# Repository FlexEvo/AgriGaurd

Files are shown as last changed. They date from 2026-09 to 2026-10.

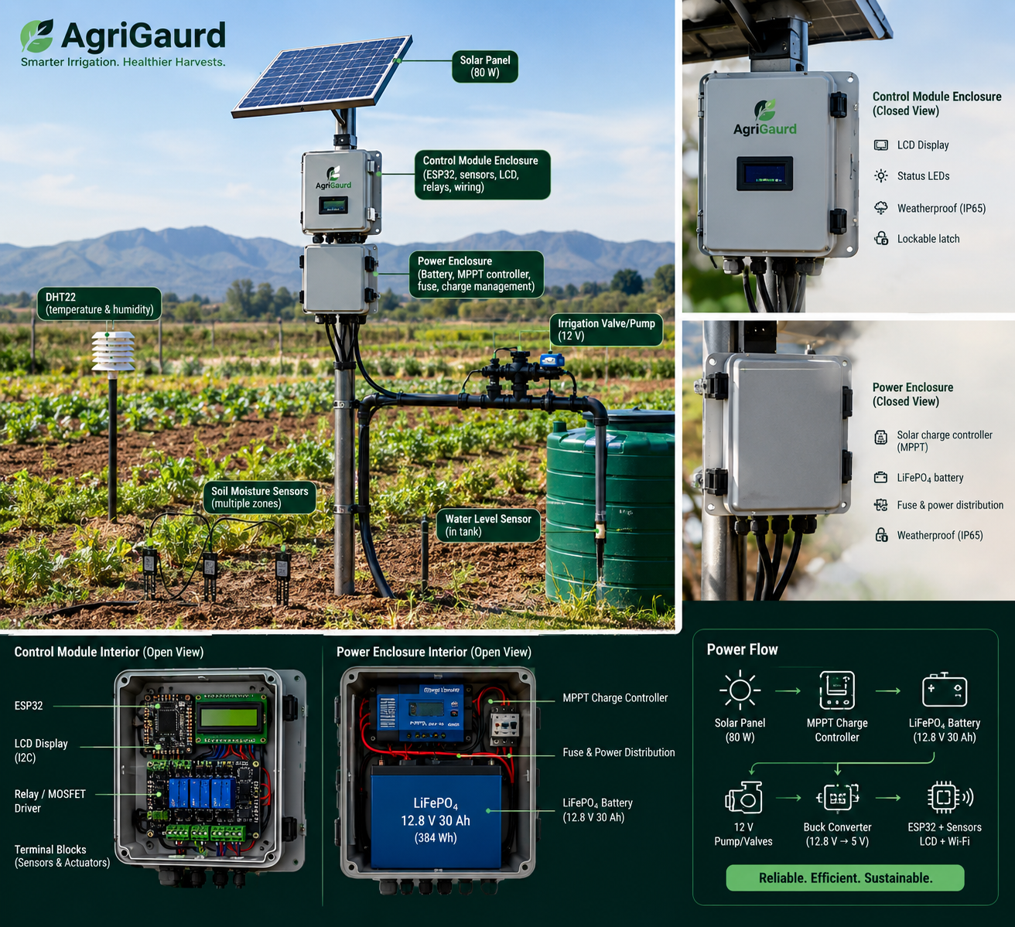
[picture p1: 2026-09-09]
Data structures/FOLDERZ_B/AgriGaurd Smart Irrigation System.png

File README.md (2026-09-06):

# 🌱 AgriGuard — Smart Irrigation & Water Management System

AgriGuard is a smart irrigation system designed to help small-scale farmers **use water more efficiently while maintaining suitable soil conditions for crop growth**.

The system combines soil-moisture sensing, environmental monitoring, automated irrigation, weather information, and historical irrigation data to make better decisions about **when, where, and how much water should be supplied**.

Rather than relying on a simple fixed irrigation schedule, AgriGuard is being developed toward an **adaptive, zone-based irrigation system** that can learn the behaviour of individual areas of a farm and use that information to improve future irrigation decisions.

---

## 🎯 Project Objective

The main objective of AgriGuard is:

> **To reduce unnecessary water consumption while providing crops with the water they need.**

Traditional automated irrigation systems can operate using fixed timers or simple moisture thresholds. While this works, it does not account well for differences between zones, soil types, environmental conditions, or available water.

AgriGuard addresses this by building an irrigation profile for each zone.

The system considers factors such as:

* Soil moisture
* Soil type
* Temperature
* Humidity
* Rainfall/weather conditions
* Soil drying rate
* Irrigation duration
* Water consumption
* Available tank water
* Historical irrigation behaviour

These factors are used to make more informed irrigation decisions.

---

# 🧠 How the Solution Works

At a high level, AgriGuard follows this process:

```text
             ┌─────────────────────┐
             │      Sensors        │
             │                     │
             │ Soil Moisture       │
             │ Temperature         │
             │ Humidity            │
             │ Water Level         │
             │ Flow Rate           │
             └──────────┬──────────┘
                        │
                        ▼
             ┌─────────────────────┐
             │       ESP32         │
             │   Control System    │
             └──────────┬──────────┘
                        │
          ┌─────────────┼─────────────┐
          ▼             ▼             ▼
   Soil Analysis   Environment    Water Status
          │             │             │
          └─────────────┼─────────────┘
                        ▼
             ┌─────────────────────┐
             │ Irrigation Decision │
             │      Algorithm       │
             └──────────┬──────────┘
                        │
                        ▼
             ┌─────────────────────┐
             │   Zone Control      │
             │                     │
             │ Valve / Pump        │
             └──────────┬──────────┘
                        │
                        ▼
                 Irrigation Cycle
                        │
                        ▼
             ┌─────────────────────┐
             │ Historical Data     │
             │ & Zone Profile      │
             └──────────┬──────────┘
                        │
                        ▼
             Improve Future Decisions
```

---

# ⚙️ System Architecture

AgriGuard is divided into several major sections.

### 1. Soil Monitoring

Capacitive soil-moisture sensors are used to monitor the moisture condition of different irrigation zones.

The system does not treat the raw sensor reading as a direct percentage. Instead, calibration values are used to convert sensor readings into a more meaningful moisture representation.

The calibration process considers conditions such as:

* Dry soil
* Wet soil
* Soil type
* Sensor behaviour

Multiple sensors can be deployed across different zones to provide a more representative view of the farm.

---

### 2. Environmental Monitoring

Environmental conditions can affect how quickly soil loses moisture.

AgriGuard therefore incorporates environmental data such as:

* Temperature
* Relative humidity
* Precipitation
* Weather forecasts

Weather data is treated as an **additional decision-making factor rather than a single point of failure**.

If weather data is unavailable, the system can continue operating using the locally measured sensor data.

---

### 3. Zone-Based Irrigation

The farm is divided into irrigation zones.

Each zone can have its own:

* Soil type
* Moisture readings
* Drying behaviour
* Irrigation history
* Valve status
* Irrigation duration
* Water consumption
* Calibration values

This allows AgriGuard to recognise that different areas of a farm may require different irrigation strategies.

For example:

```text
Zone 1 → Sandy soil → dries quickly
Zone 2 → Loamy soil → moderate drying
Zone 3 → Clay soil  → dries slowly
```

Instead of treating the entire farm identically, the controller can make decisions based on the behaviour of each zone.

---

# 💧 Adaptive Irrigation

One of the main developments of AgriGuard is moving beyond a simple:

```text
IF soil is dry
    irrigate
```

approach.

The system is being developed to consider both **current conditions and historical behaviour**.

A simplified decision can be represented as:

```text
Current Soil Condition
          +
Environmental Conditions
          +
Zone Drying Behaviour
          +
Expected Weather
          +
Available Water
          ↓
   Irrigation Decision
```

This creates the foundation for adaptive irrigation.

---

# 📈 Zone Irrigation Profile

AgriGuard records information about how each irrigation zone behaves over time.

The zone profile can include:

* Moisture readings
* Moisture change over time
* Drying rate
* Temperature during drying
* Irrigation duration
* Irrigation frequency
* Water used
* Previous irrigation cycles

The purpose is to determine patterns such as:

> "How quickly does this zone dry after irrigation?"

and:

> "How much water does this zone normally require?"

This information can then be used to improve future irrigation decisions.

---

# 💦 Water Budget

Another major component of AgriGuard is the **water budget**.

The system considers:

```text
Available Water
       ↓
Water Required by Zones
       ↓
Zone Priority
       ↓
Water Allocation
       ↓
Irrigation
```

This is particularly important when the available water supply is limited.

Instead of simply irrigating every zone whenever its moisture falls below a threshold, AgriGuard can determine how available water should be allocated.

The long-term goal is to answer:

> **"Given the amount of water currently available, where will using that water provide the greatest benefit?"**

---

# 🧠 Learning Irrigation Cycles

AgriGuard is being developed toward a system that can learn from previous irrigation cycles.

After an irrigation event, the system can monitor:

```text
Irrigation starts
       ↓
Water is supplied
       ↓
Irrigation stops
       ↓
Soil moisture is monitored
       ↓
Drying rate is calculated
       ↓
Data is stored
       ↓
Future irrigation decisions improve
```

This allows the system to gradually build an understanding of each zone rather than relying entirely on manually configured values.

---

# 🚨 Safety System

AgriGuard also includes an emergency-stop mechanism.

The emergency stop is designed to provide a physical safety mechanism capable of shutting down the irrigation system when activated.

The emergency function is treated separately from the normal irrigation decision logic so that safety takes priority.

Conceptually:

```text
              Emergency Stop
                    │
                    ▼
          ┌──────────────────┐
          │ System Shutdown  │
          └────────┬─────────┘
                   │
          Normal operation
             is disabled
```

The design also considers the interaction between the physical latching switch, ESP32 control logic, and irrigation power-control circuitry.

---

# 🔌 Hardware

The system has been designed around an **ESP32 development board** as the main controller.

Major hardware components include:

* ESP32 development board
* Capacitive soil-moisture sensors
* Temperature/humidity sensor
* Water-level sensor
* Water-flow sensor
* Solenoid/flow valves
* Pump/control circuitry
* LCD display
* Emergency-stop switch
* Power supply
* Protective sensor enclosures

The exact hardware configuration may evolve as the prototype is developed and tested.

---

# 💻 Software

The embedded software is being developed primarily using **C++ for the Arduino/ESP32 environment**.

The software is structured into separate functional sections so that each subsystem can be developed and tested independently before being integrated into the main program.

Major software components include:

```text
Sensor acquisition
      ↓
Data processing
      ↓
Calibration
      ↓
Zone management
      ↓
Drying-rate analysis
      ↓
Weather processing
      ↓
Irrigation decision
      ↓
Valve control
      ↓
Water-budget management
      ↓
Historical data
```

Data structures such as `enum` and `struct` are used to represent things such as:

* Soil types
* Irrigation zones
* Water tanks
* Sensor data
* Valve states
* Calibration parameters

This makes the system easier to expand as additional zones and sensors are introduced.

---

# 🌦️ Weather Integration

AgriGuard can retrieve weather information through an online weather API.

The weather subsystem has been designed to provide information such as:

* Temperature
* Relative humidity
* Precipitation
* Probability of precipitation

This information can be incorporated into irrigation decisions.

For example, if a zone is approaching its irrigation threshold but significant rainfall is expected, the system can consider reducing or delaying irrigation.

Weather information therefore acts as a **decision-enhancement layer**, rather than being required for the system to function.

---

# 🛠️ Development Approach

The system has been developed incrementally rather than attempting to build the complete system at once.

The development process has broadly followed:

```text
1. Identify the irrigation problem
            ↓
2. Select sensors and hardware
            ↓
3. Develop individual sensor modules
            ↓
4. Develop ESP32 control logic
            ↓
5. Develop soil calibration
            ↓
6. Introduce multiple irrigation zones
            ↓
7. Add environmental data
            ↓
8. Develop irrigation thresholds
            ↓
9. Implement water monitoring
            ↓
10. Measure irrigation cycles
            ↓
11. Build zone irrigation profiles
            ↓
12. Develop water budgeting
            ↓
13. Introduce adaptive/learning behaviour
            ↓
14. Integrate safety systems
            ↓
15. Package the system into physical hardware
```

The project therefore combines **embedded systems, electronics, software engineering, data processing, control systems, and physical product design**.

# 🚀 Long-Term Vision

The long-term goal of AgriGuard is not simply to automate irrigation.

It is to create a system that can **understand how a farm uses water and continuously improve how that water is allocated.**

The intended progression is:

```text
Automated Irrigation
        ↓
Zone-Based Irrigation
        ↓
Data-Driven Irrigation
        ↓
Adaptive Irrigation
        ↓
Water-Budget Optimisation
        ↓
Self-Improving Irrigation System
```

AgriGuard is therefore being developed as a platform where **sensing, control, data and physical infrastructure work together** to make irrigation more efficient.

---

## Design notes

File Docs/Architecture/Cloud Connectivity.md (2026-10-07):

# AgriGuard Cloud Connectivity Architecture

## Principle

Cloud connectivity is an enhancement layer, not a safety dependency.

```
                    AGRIGUARD ESP32
                         |
          +--------------+--------------+
          |                             |
          v                             v
   LOCAL CONTROL                 CLOUD CLIENT
          |                             |
   +------+------+              +-------+-------+
   |      |      |              |       |       |
 Soil   Tank   Valves          Wi-Fi   NTP   HTTPS
   |      |      |                      |
   +------+------+                      v
          |                     Supabase Edge Function
          |                              |
          |                     Atomic telemetry ingest
          |                              |
          v                              v
    SAFE IRRIGATION              Supabase telemetry
```

## Failure behavior

If Wi-Fi or the cloud service becomes unavailable:

1. Local soil monitoring continues.
2. Tank monitoring continues.
3. Valve/safety logic continues.
4. Cloud telemetry is marked offline.
5. The device retries according to the configured retry policy.
6. Reconnection does not require a device reboot.

## B6 retry policy

The current test configuration uses:

- maximum POST attempts: 3
- HTTP timeout: 10 seconds
- retry delays: 2 seconds, then 4 seconds
- automated Wi-Fi outage test
- automatic Wi-Fi reconnection

## B7 heartbeat

The heartbeat provides device-health information such as:

- firmware version
- uptime
- Wi-Fi state
- Wi-Fi RSSI
- cloud state
- consecutive cloud failures
- last successful cloud transmission

A successful heartbeat also updates the device's server-side last-seen information.

## Next milestone

After the corrected B6/B7 sketch receives a successful HTTP 2xx response and the corresponding Supabase rows are verified, B1-B7 can be marked as end-to-end verified.

The next major workstream is the farmer-facing profile/onboarding flow.

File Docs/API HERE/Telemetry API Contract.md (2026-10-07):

# AgriGuard Telemetry API Contract

## Endpoint

`POST /functions/v1/ingest-telemetry-v2`

The device authenticates using custom headers.

## Required headers

| Header | Purpose |
|---|---|
| `x-device-uid` | Provisioned device identifier |
| `x-device-key` | Private device credential |
| `x-request-id` | RFC 4122 UUID request identifier |
| `x-device-nonce` | Per-request replay-protection nonce |
| `x-device-timestamp` | Unix timestamp in milliseconds |

## Freshness

The Edge Function currently accepts authenticated request timestamps within approximately five minutes of server time.

## Telemetry structure

```json
{
  "heartbeat": true,
  "sensor_readings": [
    {
      "zone_id": "ZONE_UUID",
      "moisture_percent": 67.89,
      "raw_value": 1778,
      "temperature_c": 13.0,
      "humidity_percent": 63.0,
      "drying_rate": 7.96,
      "recorded_at": "2026-10-06T23:55:32Z"
    }
  ],
  "tank_reading": {
    "level_percent": 75.0,
    "volume_l": 3937.5,
    "distance_cm": 45.0,
    "recorded_at": "2026-10-06T23:55:32Z"
  },
  "system_status": {
    "status": "online",
    "message": "AgriGuard B6/B7 test",
    "battery_percent": 100,
    "wifi_rssi": -50,
    "recorded_at": "2026-10-06T23:55:32Z"
  }
}
```

## Accepted system states

- `online`
- `offline`
- `watering`
- `settling`
- `checking`
- `emergency_stop`
- `fault`

## Validation notes

- Sensor arrays may contain up to three readings per request.
- Zone IDs must be valid UUIDs and must belong to the authenticated device and its farm.
- Percentages must be between 0 and 100.
- Raw sensor values must be non-negative integers.
- Tank volume and distance must be non-negative.
- Wi-Fi RSSI must be zero or negative.
- `recorded_at` values must be valid and fresh.

## Response

Successful ingestion returns an `ok: true` response and a server-side receipt timestamp.

Failures are mapped to meaningful HTTP responses, including:

- `400` invalid payload
- `401` authentication/device state failure
- `403` unauthorized zone
- `409` replay detected
- `429` device rate limit exceeded

## Credential rule

Device credentials and farmer authentication are separate security domains.

The ESP32 device key must never be used as a farmer login credential and must never be committed to GitHub.

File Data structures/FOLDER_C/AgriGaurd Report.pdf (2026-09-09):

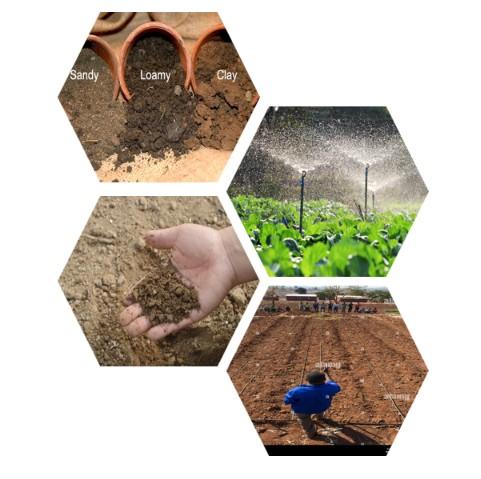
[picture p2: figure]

## AgriGaurd

## System

Table of Contents

# Problem Statement…

### 1. Background and Problem Statement

Agriculture is fundamentally dependent on water. However, water availability is becoming increasingly uncertain due to population growth, climate variability, drought and increasing competition for freshwater resources.
Agriculture currently accounts for approximately 72% of global freshwater withdrawals, with irrigation being the primary driver of agricultural water demand. At the same time, approximately 1.2 billion people live in agricultural areas experiencing severe water constraints. The Food and Agriculture Organization (FAO) estimates that by 2050 agriculture will need to produce approximately 50% more food, feed and fibre than in 2012, while freshwater demand is expected to increase by another 25%.
This creates a fundamental challenge that agriculture needs to produce more with less water. The problem is therefore not simply a shortage of water. It is also a problem of “how available water is managed and allocated.”

# The Irrigation Problem

Traditional irrigation decisions are often based on fixed schedules, timers, manual observation or farmer experience. A simplified conventional approach would look like:

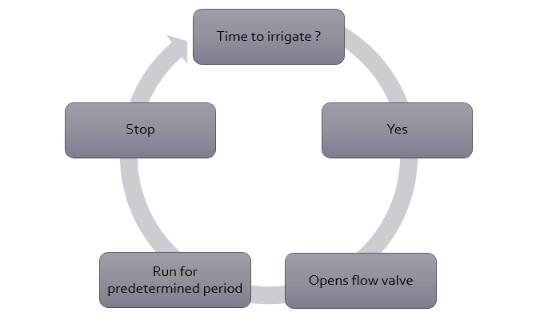
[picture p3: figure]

The problem with this approach is that the environment is not fixed, soil moisture changes continuously, temperature fluctuates, humidity changes, rainfall changes, different soils retain water differently, different zones/areas dry at different rates. Consequently, applying the same irrigation schedule to every zone can result in:
- Under-irrigation
- Over-irrigation
- Unnecessary water consumption
- Nutrient leaching
- Waterlogging
- Reduced crop performance
- Increased operating costs

The central problem identified by AgriGuard is that farmers need to make irrigation decisions using changing field conditions, but many low- and mid-scale operations lack affordable systems capable of continuously measuring, interpreting and acting on those conditions.

# How Much Water Is Being Lost

Irrigation losses occur for many reasons, including evaporation, runoff, deep percolation, poor infrastructure and inappropriate irrigation scheduling.
FAO (Farm and Agriculture Organization) indicates that 40% or more of water diverted for irrigation can be lost at farm level in some circumstances, through mechanisms such as deep percolation and surface runoff.
This does not mean that 40% of all irrigation water is universally wasted by farmers. Rather, it demonstrates the magnitude of potential losses throughout irrigation systems. Research provides stronger evidence that better scheduling can directly reduce water use. A systematic review of soil-water-sensor irrigation scheduling research found that sensor-based scheduling used, on average:

The review also found that soil-water-sensor scheduling produced 24% higher yields on average compared with traditional scheduling in the relevant comparisons. This provides an important foundation for AgriGuard, better information can result in better irrigation decisions.

Comparison | Average water reduction
Traditional scheduling | 38%
Computer-model scheduling | 16%
Evapotranspiration replacement | 20%
Canopy-temperature methods | 1%
Traditional scheduling | 38%

# Overwatering Is Also a Problem

Water conservation cannot simply mean reducing irrigation as much as possible. Plants require water, but they also require oxygen around their roots. When soil remains saturated for extended periods, oxygen availability to the root system decreases. This can impair root growth, nutrient uptake and plant development.
A global meta-analysis containing 2,419 comparisons from 115 studies found that waterlogging reduced crop yield by an average of approximately 32.9%.
Therefore, both extremes are problematic:

OR

This leads to one of the core principles behind AgriGuard:
The objective is not to give crops more water, but it is to give crops the right amount of water at the right time.

# Why Small-Scale Farmers Are Particularly Affected

The irrigation problem becomes more difficult when considering the economic and environmental conditions faced by small and mid-scale farmers.
A 2025 review specifically examining smallholder irrigation development in South Africa identified several constraints, including:
- Limited access to irrigation water
- Inadequate infrastructure
- Drought
- Limited land access
- Financial constraints
- Technological limitations
- Knowledge and skills gaps
- Challenges implementing water policies
- Climate-change impacts
These constraints interact with one another.

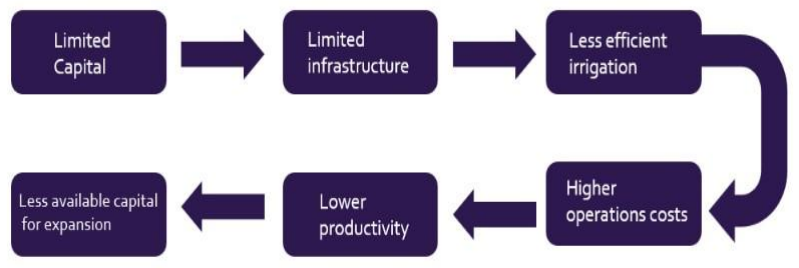
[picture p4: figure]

This creates a cycle that makes it difficult for small-scale farmers to transition toward more advanced agricultural operations.

# Economic Constraints

Small-scale farmers commonly face barriers associated with:
- Initial capital:
Advanced irrigation systems can require pumps, pipes, valves, sensors, controllers and installation.
- Operating costs:
Energy, water, maintenance and replacement components add recurring costs.
- Access to finance:
Agricultural lending can be difficult because small farms may lack collateral, have small transaction sizes and face high production and market risks.
Research on agricultural finance in Africa notes that less than 4% of total commercial bank lending goes to agriculture, with factors such as lack of collateral, remoteness, infrastructure limitations and variable rainfall contributing to lending difficulties.
- Technology cost:
Advanced precision-agriculture systems can provide excellent functionality, but their cost and complexity can make them difficult to adopt at smaller scales.

# Environmental Constraints

Small-scale farmers are also exposed to environmental uncertainty. These include:
- Drought
- Unpredictable rainfall
- Increasing temperatures
- Evaporation
- Soil variability
- Water scarcity
- Changing crop-water requirements
Climate change makes the problem more difficult because water supply becomes less predictable while crop water demand can increase. The FAO identifies climate change as a factor reducing the reliability of water supply while increasing crop water requirements. Therefore, a farmer cannot reliably depend on a fixed irrigation schedule throughout an entire growing season.

# Research Supporting the AgriGuard Concept

AgriGuard's architecture was influenced by several areas of existing research.
Research strongly supports the use of soil-water sensors for irrigation scheduling.
A 2023 systematic review analysed 97 papers, including 48 studies involving soil-water-sensor irrigation scheduling. The review found that sensor-based scheduling reduced water use while maintaining or improving yield in many comparisons.
Importantly, the review also identified calibration as one of the major factors influencing sensor accuracy. This directly influenced AgriGuard's decision not to treat a raw sensor ADC data as an automatically valid percentage.
“A percentage is only useful if we know what 0% and 100% actually mean.”

# Study on Smart Irrigation

Study into smart irrigation has expanded significantly.
A 2026 systematic review of IoT-enabled smart irrigation systems examined 50 studies and reported water savings ranging from approximately 9–50% across reviewed systems relative to conventional irrigation. The same review identified high cost, scalability and farmer training among major adoption barriers.
This is significant because it demonstrates both sides of the problem, which is that the technology works, but also the technology must also be accessible.
AgriGuard therefore attempts to combine the advantages of smart irrigation with a low-cost embedded architecture.

# Introducing AgriGuard

AgriGuard is an ESP32-based smart irrigation and water-management system designed for low to mid-scale agricultural operations.
The system consists of:
✓ | ESP32 MCU
✓ | 3 × capacitive soil-moisture sensors
✓ | 3 × solenoid irrigation valves
✓ | 4-channel relay module
✓ | Water-level sensor
✓ | LCD I2C
✓ | ON/OFF switch
✓ | Emergency-stop switch
✓ | Reset switch
✓ | Pull-up resistors
The prototype is organised around three irrigation zones. Zone 1 → Soil Sensor 1 → Valve 1
Zone 2 → Soil Sensor 2 → Valve 2
Zone 3 → Soil Sensor 3 → Valve 3
The ESP32 acts as the central processing and control unit. How AgriGaurd works:

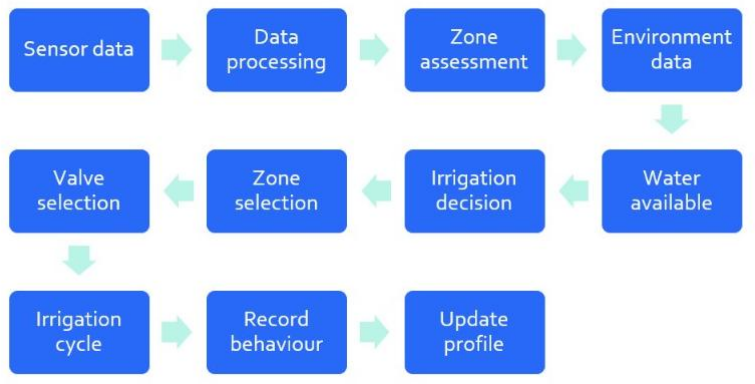
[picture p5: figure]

# . What AgriGuard Considers

AgriGuard is designed to consider several factors simultaneously. ✓ Current soil moisture:
Determines the current soil moisture of each zone.
✓ Soil type
Considers the differences in how different soils retain and release water. ✓ Drying rate
Determines how the rate at which each zone is losing moisture.
✓ Temperature
Considers how cold or hot the area is can influence the drying rate of the farm.
✓ Humidity
Looks at the moisture within the air to determine the amount of water that has left. ✓ Rainfall/weather
Can influence whether irrigation should be delayed or adjusted.
✓ Available water
Determines whether there is sufficient water in the tank for irrigation.
✓ Historical irrigation cycles
Provides information about how the zone responded to previous irrigation events.
✓ Zone priority
Allows available water to be allocated according to the current needs of different zones

# AgriGuard and Small-Scale Farmer Constraints

AgriGuard is designed specifically to help resolve the issues farmers were encountering.

AgriGuard is not attempting to solve every agricultural problem, instead, it focuses on a specific and controllable problem. Improving irrigation decision-making and water allocation.

Farmer constraint | AgriGuard response
Limited capital | Low-cost ESP32-based architecture
Limited irrigation infrastructure | Modular zone-based design
Water scarcity | Water-level monitoring and water budgeting
Unpredictable weather | Weather-assisted decision-making
Different soil types | Zone-specific calibration
Different drying rates | Drying-rate analysis
Limited technical resources | Local LCD interface
Safety concerns | Physical E-STOP and reset
Internet unreliability | Local sensor operation remains available
Need for expansion | Modular zone architecture
Limited historical data | System progressively builds irrigation profiles

# Innovation

The biggest innovation in AgriGuard is not simply automatic irrigation, it is the system's development in learning-based water budget.
The system can progressively learn:
- How quickly each zone dries
- How much irrigation each zone normally requires
- How long irrigation cycles run
- How environmental conditions influence drying
- How much water is available
- How much water different zones require
This creates the possibility of moving from, “Turn the valve on when the soil is dry", to determining on what I have learned about this zone, the current environmental conditions and the amount of water available, this zone should receive priority.
The long-term vision is to create a self-improving irrigation system.
The conceptual progression is:

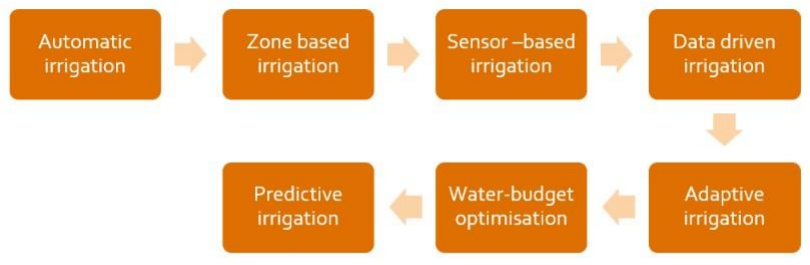
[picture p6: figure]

Future versions could use machine-learning models to predict soil moisture using historical:
- Soil moisture
- Temperature
- Humidity

- Weather
- Irrigation duration
- Water usage
Recent research is already investigating exactly this direction: soil-moisture forecasting models using historical sensor, weather and irrigation observations. The major change would be that AgriGuard would no longer wait for soil to become sufficiently dry before reacting, it would predict when a zone is likely to require water and prepare the water budget before the demand occurs.

# System Architecture

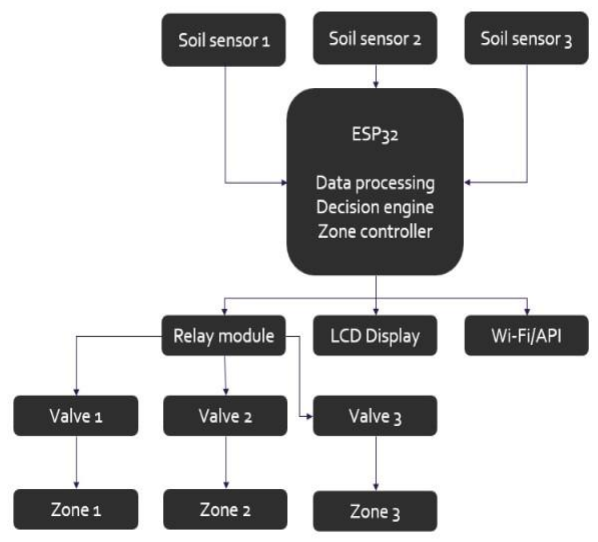
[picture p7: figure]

Water-Level Sensor ──► ESP32

ON/OFF ───────────────► ESP32 E-STOP ───────────────► Safety Logic RESET ────────────────► ESP32

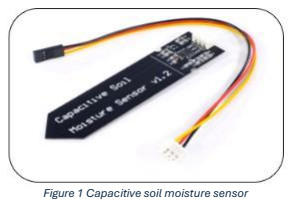
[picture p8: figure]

## Soil-Monitoring Subsystem

Three capacitive sensors provide the soil-moisture information. Each sensor is assigned to one zone. The raw analogue signal is processed by the ESP32 and converted using calibration information. The system can then monitor changes over time. This provides the basis for calculating drying rates.

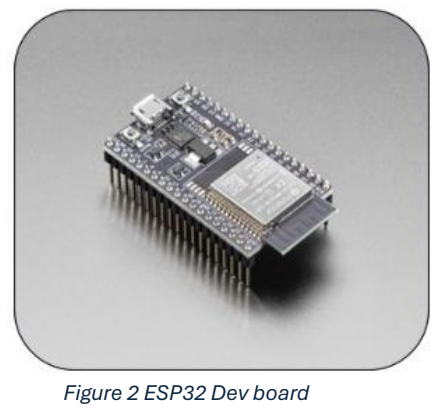
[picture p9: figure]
Figure 2 ESP32 Dev board

## Irrigation-Control Subsystem

The ESP32 is the brains of the entire operations, it handles all logical, arithmetic calculation and all processing the system will perform. The ESP32 is a (Come up with something explain how the ESP32 is used in the system).

## Relay module

The ESP32 cannot directly drive the irrigation valves. The relay module therefore acts as the interface between the controller and the valve circuits. (Say something about how the relay works and how it is used in this system).

## Battery

Provides power to the entire system.

Figure 1 Capacitive soil moisture sensor

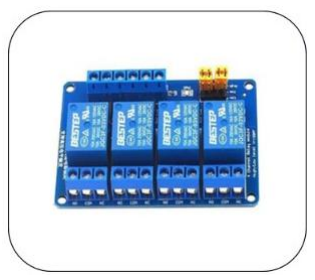
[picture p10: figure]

Figure 3 4-Channel relay module

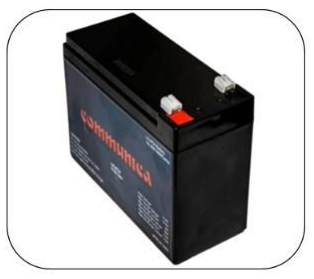
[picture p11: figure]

Figure 4 12V Battery

## Water-Level Subsystem

The ultrasonic water-level sensor provides information about the available water supply.
This becomes an input into the water-budget system. (Same something about how the ultrasonic water level sensor is used in the system)

## Weather Subsystem

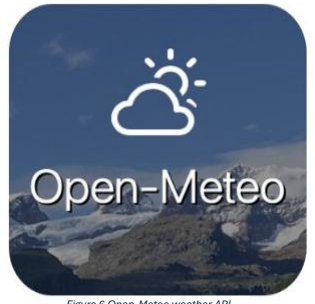
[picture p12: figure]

The ESP32's Wi-Fi capability allows the system to retrieve external weather information.
Potential inputs include:
- Temperature
- Relative humidity
- Precipitation
- Precipitation probability
Weather information can modify the irrigation decision but does not replace local soil measurements. (Talk about how we use open-Mateo to get weather data and how using it is way better for our system)

## Flo sensor Subsystem

With a flow sensor valve, we can determine the amount of water that was used in a specific zone. With that information we can predict how much water will zone 1 need in the next hour. Flow sensor also provides the ability to control irrigation of each zone.

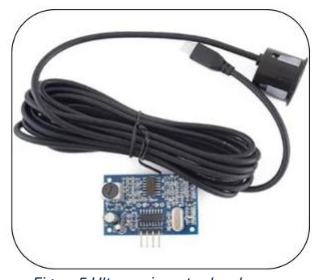
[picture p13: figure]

Figure 5 Ultrasonic water-level sensor

Figure 6 Open-Mateo weather API

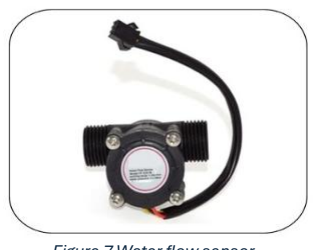
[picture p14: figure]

Figure 7 Water flow sensor

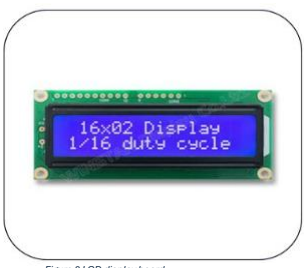
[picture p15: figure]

## User Interface Subsystem

The LCD provides local feedback.

The operator can view information such as: ZONE 1: 43%
ZONE 2: 67%
ZONE 3: 51%
TANK: 74%
STATUS: NORMAL
The display allows the farmer to interact with the system without requiring a computer.

## Safety Subsystem

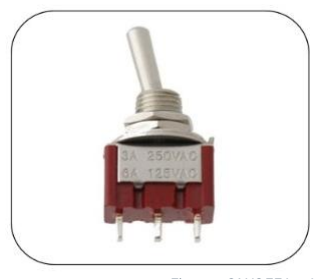
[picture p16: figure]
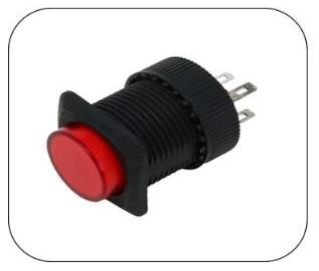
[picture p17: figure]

AgriGuard incorporates
three physical controls

ON/OFF
Controls normal
operation.
E-STOP
Places the system into a
safe state.
RESET
Allows controlled recovery.
The intended sequence is:
Normal Operation ➔ Emergency Detected ➔ E-STOP ➔ Safe State ➔ Problem-Corrected ➔ RESET➔ Normal Operation

Figure 8 LCD display board

Figure 9 ON/OFF latch and E-STOP switches

# Development Challenges

Building AgriGuard was not simply a matter of connecting sensors to an ESP32 then everything is working. Several problems were encountered during development of the system.

## Sensor Calibration

Problem
Raw capacitive sensor values do not automatically translate into meaningful moisture percentages that we can use. Different soil types produce different readings.
Solution
A calibration approach was developed using dry and wet reference conditions. The user first places the sensors in fully dry soil to measure the soil moisture. We use that value as our reference point, then the user again places the sensor in fully wet soil to get our max moisture reading which we will use as our reference point. After we have captured the results, we can now properly convert the raw values from sensor into usable percentages we use to represent different soil moisture levels. In this system, 0% represents fully dry soil and 100% represents fully wet soil. With this knowledge, understanding the sensor readings has become easier. This was one of the reasons the project moved away from treating a raw sensor reading as an absolute percentage.

## Different Soil Types

Problem
Sandy, loamy and clay soils behave differently.
The challenge with dealing with different soil types is that each one has their own specific needs and requirements to thrive. Now knowing that, we cannot simply have a fixed threshold we use to irrigate the soil. The main factors we had to consider was the rate at which water was being retained, how fast does water leave the soil and how does temperature affect the soil.
Solution
Classify areas in the farm as zones that have different soil types. With each zone, we provide to its specific needs rather than just having a one size fits all solution. To accommodate each zones specific needs, we looked at each zones characteristics but mainly we focused on:
✓ | Soil type
✓ | Dry calibration
✓ | Wet calibration
✓ | Moisture history
✓ | Drying behaviour
Result
The system can progressively treat each zone according to its own behaviour, and also because our system has the capability of knowing what each raw value from sensor means in terms of moisture readings, we placed soil moisture sensors in each zone so we can know what each zone needs. With this technology being able to know each soil moisture of each zone has elevated the dynamic of AgriGaurd.

## Temperature Effects

Problem
Temperature affects water loss and therefore changes how quickly soil can dry. Using soil moisture alone does not explain why the same zone may dry faster on one day than another.
Solution
Temperature was introduced as an additional environmental factor. To properly determine when to irrigate, we had to refactor our irrigation logic by incorporating weather data into our irrigation logic. We used a platform called Open-Mateo to get all weather data needed to improve how we know when to irrigate.

## Threshold Determination

Problem
Since we knew that having a fixed moisture threshold is easy to implement but does not consider for:
1) Soil type
2) Weather
3) Temperature
4) Drying rate
5) Historical irrigation
6) Water availability
Solution
The system evolved toward dynamic decision-making. Instead of having:
Moisture < 40%
Irrigate
The system now considers:
✓ Moisture
✓ Drying Rate
✓ Environment
✓ Weather
✓ Water Availability
✓ Zone Profile
✓ Decision

## Water-Budget Development

Problem
Initially, the system could determine whether a zone needed water, but this did not consider “what happens when there isn't enough water for every zone?"

Solution
The water-budget concept was introduced.
The system can monitor the available tank water and compare it with estimated zone requirements. How it works is that it looks at all zones and it determines in which state each zone is in. For instance, a zone could either be:
❖ Healthy
❖ Moderate.
❖ Critical.
After determining the state of each zone, it rations the water based on the state its in, if a zone is critical, it will receive majority of the water, the moderate one will receive what’s left and the healthy one won’t be irrigated. This system gives water priority to zones that in need of water than others. This transformed the project from a simple irrigation controller into a water-management system.

## Safety Integration

Problem
Software-controlled irrigation creates a safety concern. If the software behaves incorrectly, the operator needs a physical method of stopping the system. Solution
A dedicated latching E-STOP and reset mechanism was incorporated into the architecture.
The E-STOP is given priority over normal irrigation commands. This ensures that:
The safety system does not depend entirely on the irrigation algorithm functioning correctly.

## Hardware Packaging

Problem
Agricultural electronics cannot simply be left exposed. The system must be protected against:
- Moisture
- Dust

- Soil
- Physical damage
- Outdoor environmental conditions
Solution
A dedicated enclosure is being designed using CAD and can be fabricated using 3D printing.
The enclosure provides:
- Component protection
- Cable management
- Mounting points
- Access to controls
- LCD visibility
- Serviceability
This also allows the physical design to be modified as the prototype evolves.

# Overall Impact

AgriGuard addresses the irrigation problem from several directions simultaneously. Environmental impact
- Reduces unnecessary water application
- Encourages more efficient use of available water
- Reduces risk of overwatering
- Supports water-conservation practices Agricultural impact
❖ Provides zone-specific irrigation
❖ Maintains better awareness of soil conditions ❖ Supports more consistent irrigation decisions ❖ Builds historical knowledge of zones

Economic impact
- Uses relatively accessible components
- Reduces dependence on expensive industrial automation
- Can potentially reduce unnecessary water and energy consumption
- Provides a modular architecture that can grow with the farm Technological impact
✓ | Combines embedded systems and IoT
✓ | Uses real-time sensor information
✓ | Introduces data-driven irrigation
✓ | Creates a foundation for predictive irrigation

# Conclusion

The irrigation problem facing agriculture is not simply a problem of insufficient water. It is also a problem of how available water is measured, allocated and used. Agriculture accounts for approximately 72% of global freshwater withdrawals, while climate change, increasing demand and water scarcity are placing additional pressure on agricultural systems.
Research demonstrates that poor irrigation management can result in substantial water losses, while overwatering can also negatively affect crop performance. At the same time, studies of soil-water-sensor irrigation demonstrate that better scheduling can substantially reduce water use while maintaining or improving yield.
However, the existence of advanced commercial technology does not automatically solve the problem for every farmer. Small and mid-scale farmers face constraints involving capital, infrastructure, water access, climate, technical knowledge and scalability. South African research specifically identifies these constraints as barriers to smallholder irrigation development.
AgriGuard was developed in response to this gap. The system combines: soil-moisture monitoring + zone-based irrigation + water-level monitoring + environmental data + irrigation history + safety controls + water budgeting. Its most important characteristic is its progression beyond basic automation. A conventional system may ask:

"Is the soil dry?"
AgriGuard aims to ask:
"How dry is this zone, how quickly is it drying, what environmental conditions are affecting it, how much water is available, how has this zone behaved previously, and is irrigation currently the best use of the available water?"

The immediate system provides automated, zone-based irrigation. The water budgeting is what comes next: transforming the system into a platform capable of building irrigation profiles for each zone, learning from previous irrigation cycles, managing a finite water budget and eventually predicting future water requirements.
AgriGuard is therefore not intended to be another device that simply turns irrigation valves on and off. AgriGuard is being developed as an intelligent water-management platform designed to help smaller agricultural operations make better decisions with the water they already have.

*

## Bibliography

Daniel, K., & Hartman, S. (2024, January 10). Oxford Academic. Retrieved from Oxford Academic: https://academic.oup.com/jxb/article/75/2/511/7249074?Elsevier. (2026, March). scienceDirect. Retrieved from scienceDirect: https://www.sciencedirect.com/science/article/abs/pii/S116103012500454X?FAO. (n.d.). Retrieved from FAO: https://www.fao.org/4/y5582e/y5582e04.htm?
FAO. (n.d.). Food andAgriculture Organization . Retrieved from Food andAgriculture Organization : https://www.fao.org/interactive/state-of-food-agriculture/2020/en/
Federica Carucci, Anna Gagliardi, & ORCID,Marcella . (2023, June 28). Retrieved from https://www.mdpi.com/2076-3417/13/13/7625?
Food and Agriculture Organization. (n.d.). Retrieved from Food and Agriculture Organization: https://www.fao.org/land-water/water/agricultural-water-management/water-accounting/en?utm_source=chatgpt.com
Pramanik, M. (2021, December 21). Elsevier. Retrieved from https://www.sciencedirect.com/science/article/pii/S2772375521000320?utm_source=chatgpt.com
ScienceDirect. (2010, May). Retrieved from ScienceDirect: https://www.sciencedirect.com/science/article/abs/pii/S0378377409003631?Smith, M. (n.d.). FAO. Retrieved from FAO: https://www.fao.org/4/w4367e/w4367e03.htm?

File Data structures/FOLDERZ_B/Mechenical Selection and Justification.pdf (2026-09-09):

Mechenical Selection and Justification (https://github.com/FlexEvo/AgriFlow/blob/main/Data%20structures/FOLDERZ_B/Mechenical%20Selection%20and%20Justification)

## Encapsulator Design Sources and Attribution

The AgriGuard Encapsulator was developed using existing open-source 3D-printable enclosure designs as reference designs rather than directly copying an existing enclosure. These designs were studied to understand common approaches to enclosure construction, including removable covers, internal mounting points, cable openings, ventilation and screw fastening.
Reference designs were obtained from publicly available open-source repositories and 3D-printing communities, including:
- Printables – ESP32 DevKit V1 Case: An open-source ESP32 enclosure used as a reference for protecting and mounting an ESP32 development board. The design is licensed under GNU GPL v3.0.
- Printables – Roomy ESP32 Enclosures: A larger ESP32 enclosure concept that provides additional internal space for wiring and electronics. It uses a CC BY-NC-SA 4.0 license.
- Printables – Capacitive soil moisture Encapsulator: A two-piece enclosure consisting of a printed base and removable cover, providing another reference for the physical arrangement of an ESP32 enclosure. It uses a CC BY-NC-SA license.
These designs served as engineering references and sources of design inspiration. The AgriGuard Encapsulator was subsequently adapted and redesigned around the project's specific hardware, including the ESP32 controller, relay/MOSFET circuitry, sensor connections, emergency-stop system, power connections and required cablerouting locations.
The final enclosure therefore represents a project-specific design rather than an unmodified reproduction of an existing model. Dimensions, mounting positions, openings and component arrangement were selected according to the requirements of the Agriguard system.
All external designs used for reference are acknowledged to their respective creators, and their individual licences are respected when using, modifying or redistributing any of their original CAD files.

Mechenical Selection and Justification (https://github.com/FlexEvo/AgriFlow/blob/main/Data%20structures/FOLDERZ_B/Mechenical%20Selection%20and%20Justification)

# Component Fastening

Components are mounted using integrated mounting bosses/standoffs that are incorporated into the 3D-printed enclosure. The ESP32 development board is mounted onto raised standoffs using small machine screws.
The relay/MOSFET control circuitry is mounted using separate screw holes or standoffs. The LCD/display, where applicable, is secured into a dedicated opening in the enclosure.
Larger components are positioned so that they do not interfere with one another or with the enclosure cover.
Screws allow components to be removed for maintenance or replacement without destroying the enclosure.

# Electrical Connections

The electronics are connected using insulated wires and removable connectors, rather than permanently soldering every component directly to the enclosure.
Cable-entry point is incorporated into the enclosure for connections to:
✓ Soil-moisture sensors
✓ Water-flow sensor
✓ Water-level sensor
✓ Irrigation valves/pump
✓ Power supply
✓ Emergency-stop circuit
The cable opening can be fitted with rubber grommets or cable glands to reduce cable movement and provide additional protection against dust and moisture.

# Enclosure Assembly

The general assembly process is:
CAD design → 3D print → install threaded inserts → mount electronics → connect wiring → close enclosure → test
The enclosure is designed so that the electronics can be assembled, inspected and serviced without having to redesign or reprint the entire housing.

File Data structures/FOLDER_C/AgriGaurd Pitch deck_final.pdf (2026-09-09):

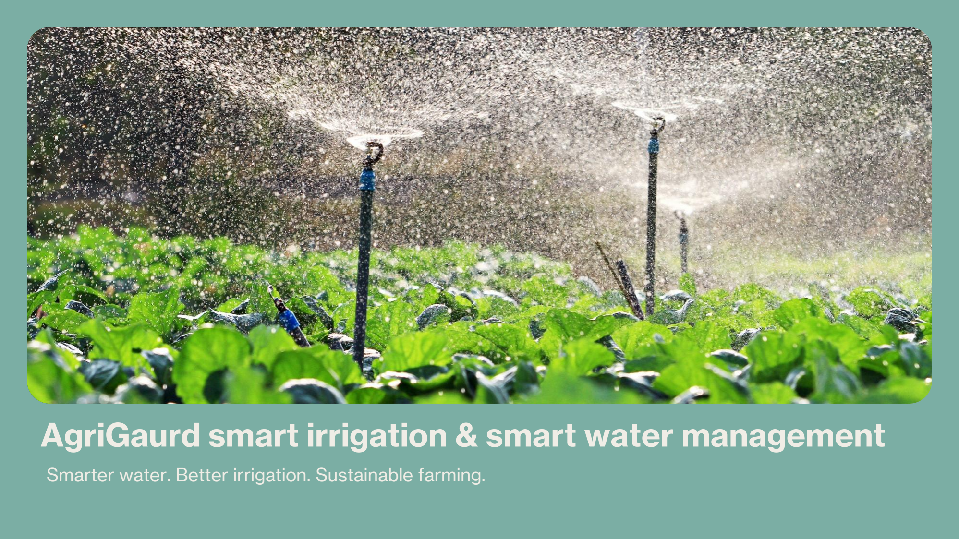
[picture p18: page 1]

# AgriGaurd smart irrigation & smart water management

Smarter water. Better irrigation. Sustainable farming.

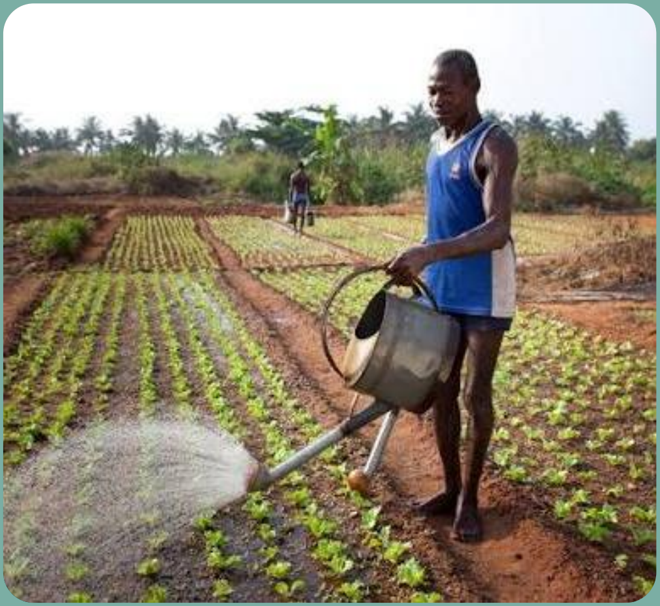
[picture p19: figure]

# Problem

Small-scale farmers face challenges such as:

1. Limited water availability
2. Inefficient irrigation practices
3. Over-irrigation and water wastage
4. Different soil types having different water requirements
5. Irrigation decisions often relying on fixed schedules
6. Limited access to affordable smart-farming technology

Question: How can we help farmers use limited water more efficiently while still providing crops with the water they need?

# Solution: AgriGaurd

AgriGuard uses real-time sensing + automated control + water management to make irrigation decisions.

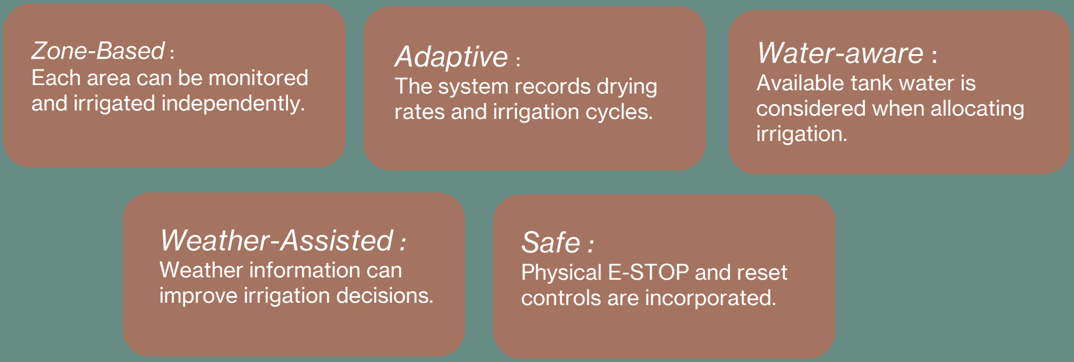
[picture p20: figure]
Zone-Based : Each area can be monitored and irrigated independently.; Adaptive :; The system records drying rates and irrigation cycles.; Water-aware :; Available tank water is considered when allocating irrigation.; Weather-Assisted :; Weather information can improve irrigation decisions.; Safe :; Physical E-STOP and reset controls are incorporated.

# Why can AgriGuard become a real product?

# Buildability

✓ The prototype uses commercially available components:
✓ ESP32
✓ Capacitive soil sensors
✓ Relay module
✓ Solenoid valves
✓ Water-level sensor
✓ LCD
✓ Standard switches and resistors

# Marketability

## ✓Vegetable growers ✓Small-scale farmers ✓Community gardens ✓Small agricultural operations ✓Water-conscious growers

# System & Technical Design

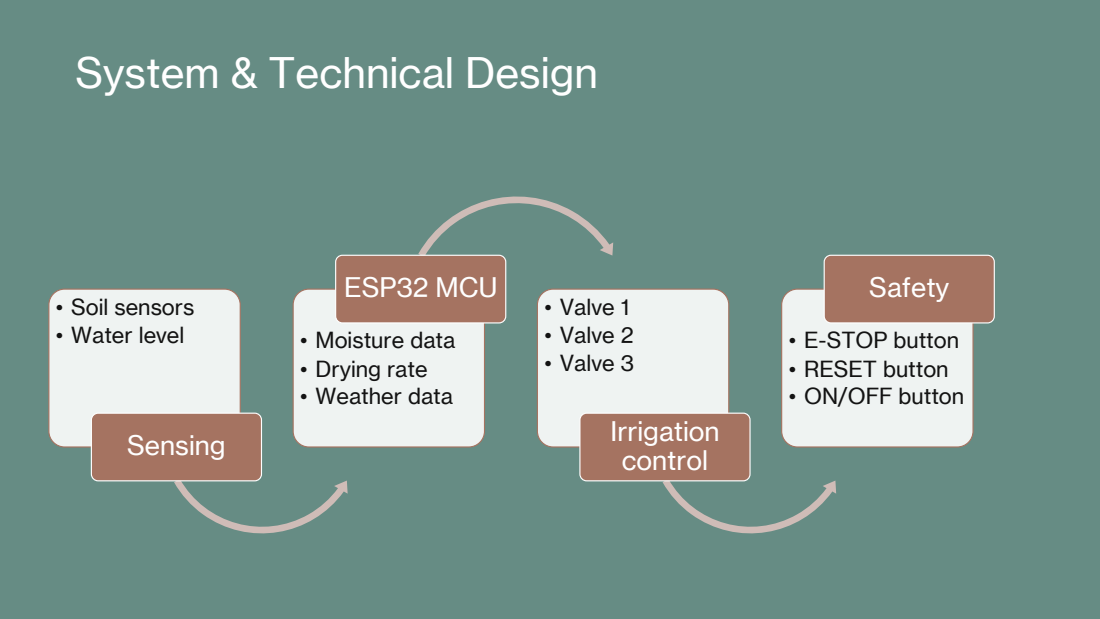
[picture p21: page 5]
• Soil sensors • Water level; Sensing; • Moisture data • Drying rate • Weather data; ESP32 MCU; • Valve 1 • Valve 2 • Valve 3; Irrigation control; Safety

• E-STOP button
• RESET button
• ON/OFF button

# Bill of components

Components | Quantity | Estimated cost
ESP32 Dev board (https://www.communica.co.za/products/bmt-esp32-s3-n16r8-ai-dev-modul?variant=53470029775148) | 1 | R 220.00
Capacitive soil sensor (https://www.communica.co.za/products/sonoff-ms01-soil-moisture-sensor?variant=39438047248457) | 3 | R 660.00
Ultrasonic sensor (https://www.communica.co.za/products/bmt-ultrasonic-sensor-hc-sr04?variant=31238518210633) | 1 | R 22.00
Solenoid irrigation valve (https://www.communica.co.za/products/hkd-g1-2in-water-flow-solenoid?variant=39345739595849) | 3 | R 276.00
4 (https://www.communica.co.za/products/bdd-relay-board-4ch-5v?variant=53464022483244)- (https://www.communica.co.za/products/bdd-relay-board-4ch-5v?variant=53464022483244)channel relay module (https://www.communica.co.za/products/bdd-relay-board-4ch-5v?variant=53464022483244) | 1 | R 50.00
LCD I2C board (https://www.communica.co.za/products/bmt-20x4-i2c-serial-lcd?variant=31901318578249) | 1 | R 103.00
ON/OFF latch switch (https://www.amazon.co.za/MTS-1-SPDT-Toggle-Switch-125VAC/dp/B0H7X6WSH2?mcid=6b7e199d023e353481dcb2b7336907b9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) | 2 | R 80.00
E (https://www.communica.co.za/products/lc2107kdet2b)- (https://www.communica.co.za/products/lc2107kdet2b)STOP latching switch (https://www.communica.co.za/products/lc2107kdet2b) | 1 | R 86.00
Pull up resistors PACK (2 (https://www.communica.co.za/products/mf-1-4w-1-e12-res-kit)- (https://www.communica.co.za/products/mf-1-4w-1-e12-res-kit)4K (https://www.communica.co.za/products/mf-1-4w-1-e12-res-kit)Ω (https://www.communica.co.za/products/mf-1-4w-1-e12-res-kit)) (https://www.communica.co.za/products/mf-1-4w-1-e12-res-kit) | 1 | R 100.00
3D printed Encapsulator( (https://www.amazon.co.za/Creality-CR-PETG-RED-Filament-Diameter/dp/B09NRZBPJ3?adgrpid=168213981055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)Fillament (https://www.amazon.co.za/Creality-CR-PETG-RED-Filament-Diameter/dp/B09NRZBPJ3?adgrpid=168213981055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)) (https://www.amazon.co.za/Creality-CR-PETG-RED-Filament-Diameter/dp/B09NRZBPJ3?adgrpid=168213981055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) | 1 | R 200.00
Tubing/piping (5m) (https://www.builders.co.za/Fasteners-and-Adhesives/Fasteners/Plastic-Tubing/Waterhouse-PVC-Tubing-Clear-5000-x-12-mm/p/000000000000780314) | 1 | R 130.00
Wiring connectors (5m) | 3 | R 78.00
Flow sensor (https://www.communica.co.za/products/bmt-g1-2in-water-flow-sensor?variant=31667842318409) | 1 | R 69.00
12V Battery | 1 | R 750.00
Total : | | R 2824.00

# AgriGaurd team lineup

Project Manager
- Oversees project architecture and system integration
- Coordinates team activities and project milestones

Project Researcher
- Researches suitable sensors and electronic components
- Evaluates component performance, cost, and suitability

Electronic & Mechanical Designer
- Designs electronic circuits and system wiring
- Develops mechanical components and enclosure designs

Embedded Systems Engineer
- Programs the ESP32 firmware
- Develops sensor-processing and irrigation algorithms

Project Documentation
- Maintains technical documentation and project reports
- Documents system designs, testing, and development

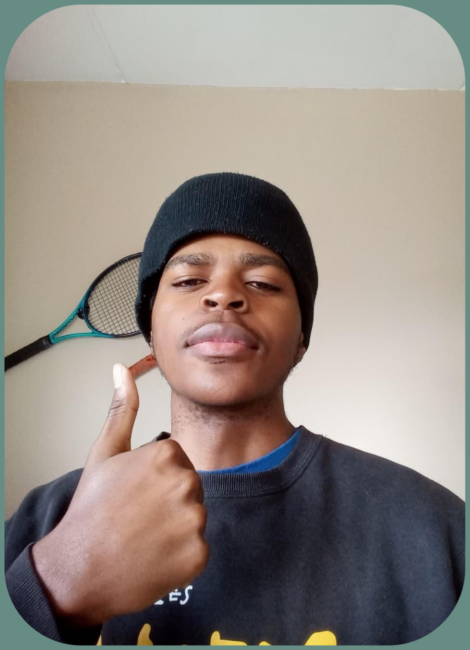
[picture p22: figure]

What does this project need: ➢ Prepares technical presentations and supporting materials GOD & Alfred

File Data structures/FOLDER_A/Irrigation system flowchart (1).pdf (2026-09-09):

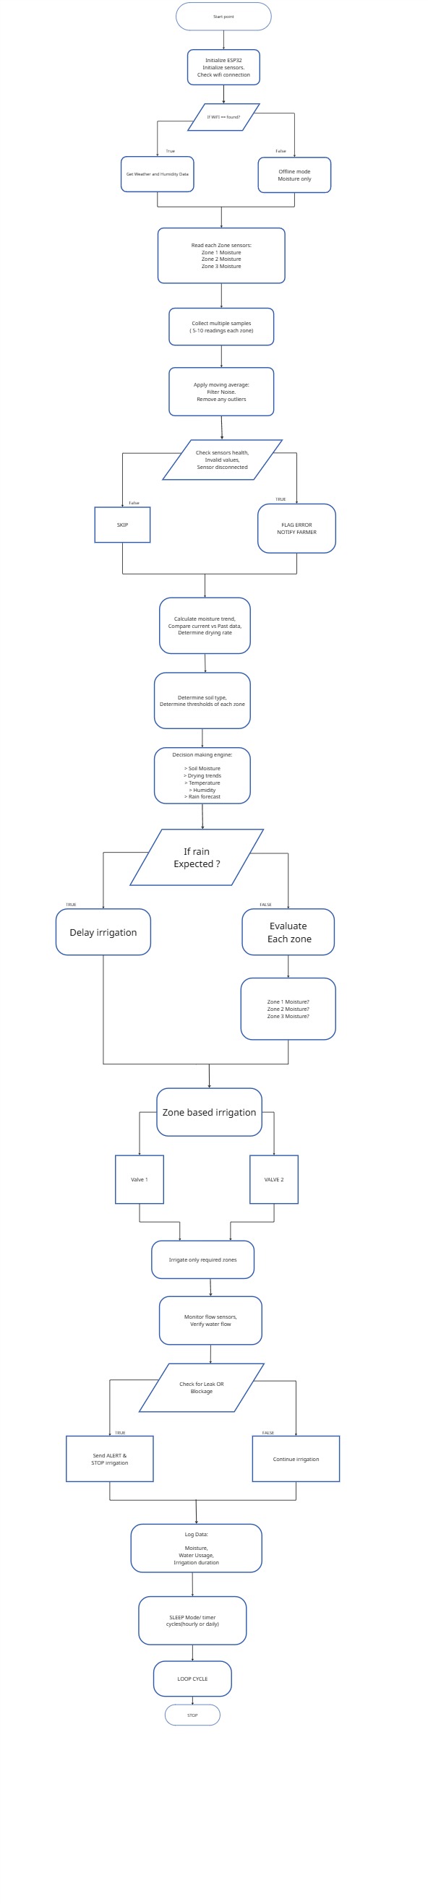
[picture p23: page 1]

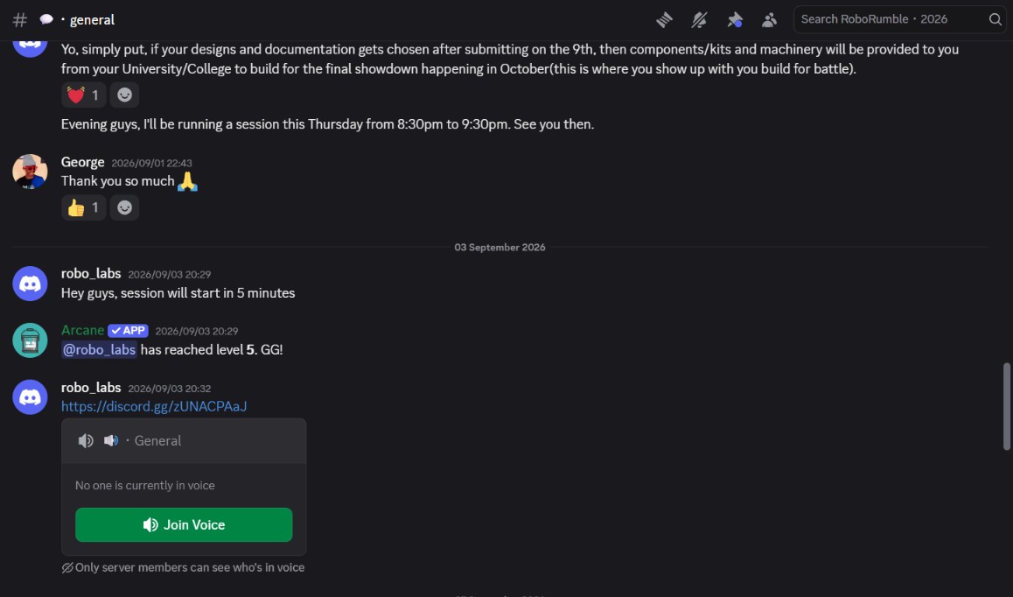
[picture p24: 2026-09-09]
Data structures/FOLDER_C/FQA_proof/proof.jpg

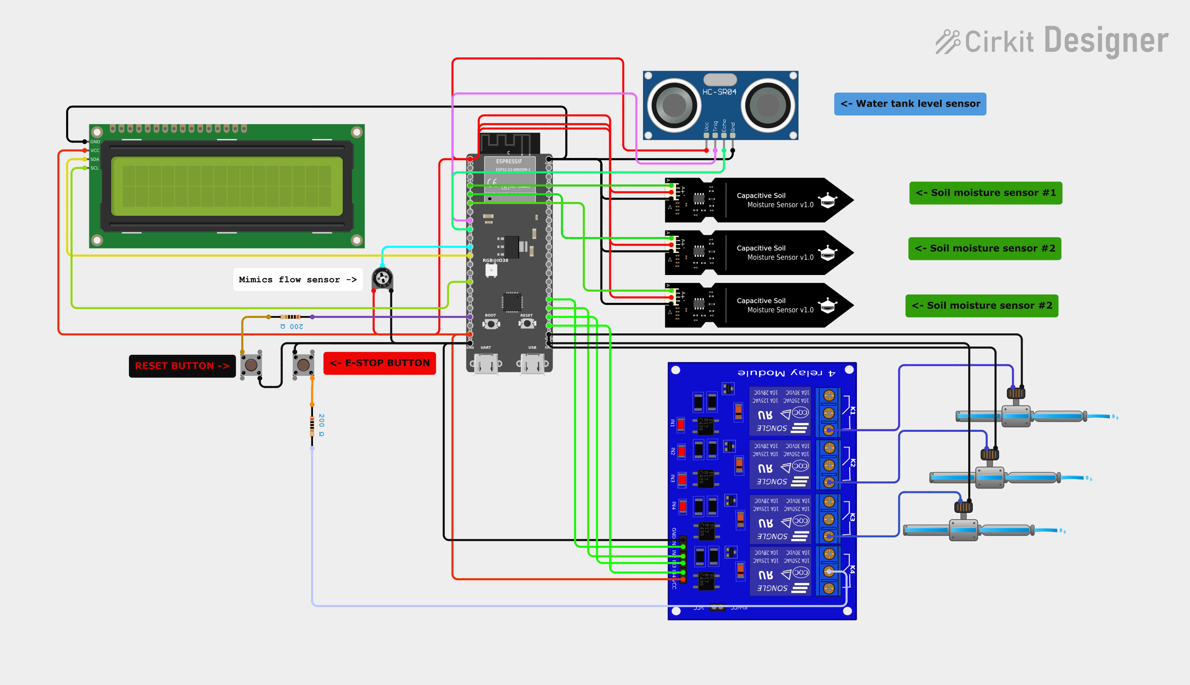
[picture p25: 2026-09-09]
Data structures/FOLDERZ_B/Agrigaurd circuit.png

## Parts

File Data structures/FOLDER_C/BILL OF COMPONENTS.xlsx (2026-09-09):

Agrigaurd Bill of components
Components | Quantity | Cost | Supplier | Stock code | Store URL
ESP32 | 1 | R 220.00 | Communica | Bmt esp32-s3 n16r8 ai dev module | Click here (https://www.communica.co.za/products/bmt-esp32-s3-n16r8-ai-dev-modul?variant=53470029775148)
Capacitive soil moisture sensor | 3 | R 660.00 | Communica | Sonoff ms01 | Click here (https://www.communica.co.za/products/sonoff-ms01-soil-moisture-sensor?variant=39438047248457)
LCD I2C board | 1 | R 103.00 | Communica | BMT 20X4 I2C SERIAL LCD | Click here (https://www.communica.co.za/products/bmt-20x4-i2c-serial-lcd?variant=31901318578249)
Ultrasonic Waterproof Sensor | 1 | R 93.00 | DIYelectronics | 9MUDISTSENW | Click here (https://www.diyelectronics.co.za/store/proximity/1181-ultrasonic-waterproof-distance-sensor-module.html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)
ON/OFF Latch switch | 2 | R 80.00 | Amazon SA | B0H7X6WSH2 | Click here (https://www.amazon.co.za/MTS-1-SPDT-Toggle-Switch-125VAC/dp/B0H7X6WSH2?mcid=6b7e199d023e353481dcb2b7336907b9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)
Solonoid valve sensor | 3 | R 276.00 | Communica | HKD G1/2IN | Click here (https://www.communica.co.za/products/hkd-g1-2in-water-flow-solenoid?variant=39345739595849)
Water flow sensor | 1 | R 69.00 | Communica | MT G1/2IN | Click here (https://www.communica.co.za/products/bmt-g1-2in-water-flow-sensor?variant=31667842318409)
Relay | 1 | R 50.00 | Communica | BDD RELAY BOARD 4CH 5V | Click here (https://www.communica.co.za/products/bdd-relay-board-4ch-5v?variant=53464022483244)
E-STOP latch switch / RESET latch | 2 | R 86.00 | Communica | LC2107KDET2B | Click here (https://www.communica.co.za/products/lc2107kdet2b)
Resistors | 1 | R 100.00 | Communica | Mf 1/4w 1% e12 res kit | Click here (https://www.communica.co.za/products/mf-1-4w-1-e12-res-kit)
M/F connector wires | 3 | R 78.00 | Communica | BMT RIBBON JUMPER 40W M/F 30cm | Click here (https://www.communica.co.za/products/bmt-ribbon-jumper-40w-m-f-30cm?variant=52644327031084)
tube (5m) | 1 | R 130.00 | Builders | 780314 | Click here (https://www.builders.co.za/Fasteners-and-Adhesives/Fasteners/Plastic-Tubing/Waterhouse-PVC-Tubing-Clear-5000-x-12-mm/p/000000000000780314)
12V Battery | 1 | R 750.00 | Communica | BATT 12,8V8 COM | Click here (https://www.communica.co.za/products/batt-12-8v8-com?variant=48247078256940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)
Fillament(3D renderings) | 1 | R 200.00 | Amazon SA | B09NRZBPJ3 | Click here (https://www.amazon.co.za/Creality-CR-PETG-RED-Filament-Diameter/dp/B09NRZBPJ3?adgrpid=168213981055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)
Total | 22 | R 2895.00

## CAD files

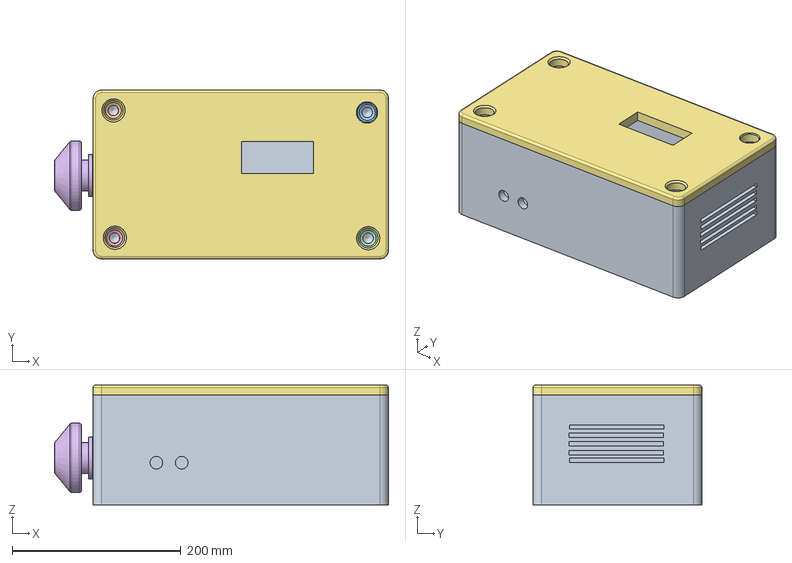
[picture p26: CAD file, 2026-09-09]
Data structures/FOLDERZ_B/Control+box.stp
395.7 x 200.0 x 142.0 mm

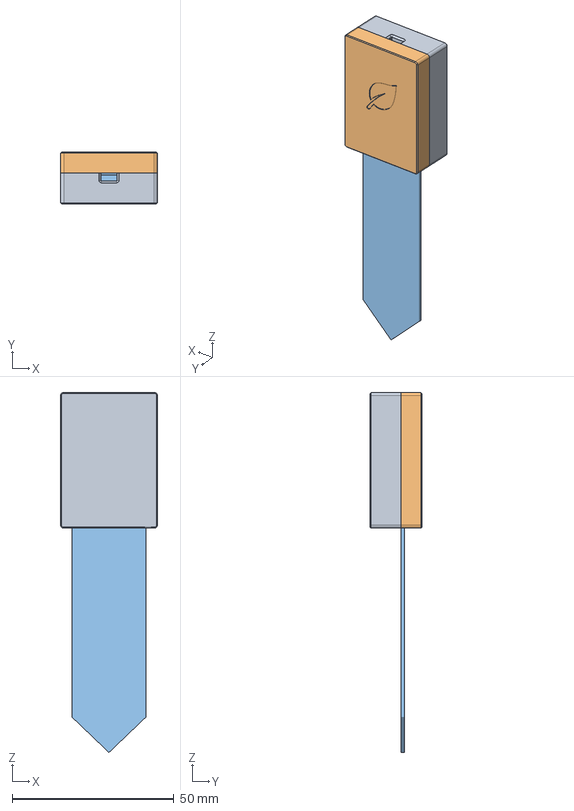
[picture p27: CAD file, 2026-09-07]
Data structures/FOLDERZ_B/soil_sensor capsule.FCStd
30.0 x 16.0 x 111.4 mm

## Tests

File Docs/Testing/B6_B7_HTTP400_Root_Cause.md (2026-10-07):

# B6 + B7 HTTP 400 Root-Cause and Verification Record

## Incident

The B6/B7 ESP32 tester could connect to Wi-Fi, synchronize NTP, establish HTTPS, and reach the Supabase Edge Function, but every telemetry POST returned HTTP 400.

The failure was therefore above the network/TLS layer.

## Root cause

The original generateUUID() function produced a request ID with this shape:

8-4-4-4-8

The Supabase Edge Function requires an RFC 4122 UUID:

8-4-4-4-12

Its validation rejects any request ID that does not match the UUID pattern.

### Corrected format

The firmware now generates:

8-4-4-4-12

with UUID version 4 and the correct variant bits.

## Telemetry timestamps

The backend currently permits omitted recorded_at values by falling back to server time, so the missing timestamps were **not the direct cause of the HTTP 400**.

They have nevertheless been added to the firmware payload so that device telemetry follows the documented API contract explicitly.

The format is:

YYYY-MM-DDTHH:MM:SSZ

## Diagnostic improvement

For every non-2xx response, the tester now prints the Edge Function response body. Future API-contract failures should therefore expose the backend's rejection reason directly in Serial Monitor.

## Verification sequence

After uploading the corrected tester:

1. Confirm Wi-Fi connection.
2. Confirm NTP synchronization.
3. Confirm each request ID is 8-4-4-4-12.
4. Confirm the nonce changes for every attempt.
5. Confirm HTTP returns a 2xx response.
6. Confirm the backend response contains ok: true.
7. Confirm the device reports cloud status as ONLINE.
8. Confirm consecutive cloud failures reset to zero.
9. Verify Supabase receives:
   - sensor readings
   - tank reading
   - system status
   - device last-seen update
   - request nonce
10. Repeat the B6 Wi-Fi outage test and confirm automatic recovery.

## Security reminder

The real device key must remain local and must never be committed to GitHub.

The repository tester intentionally contains a placeholder:

DEVICE KEY HERE

The live credential must be provisioned separately.

## Current status

- B1 NTP: implemented
- B2 configuration/credentials: implemented
- B3 UUID + nonce: corrected
- B4 telemetry model: implemented
- B5 HTTPS transport: implemented
- B6 retry + Wi-Fi recovery: implemented
- B7 heartbeat/device health: implemented
- Previous HTTP 400: root cause identified and firmware corrected
- Final live 2xx verification: **pending hardware upload with the real device credential**

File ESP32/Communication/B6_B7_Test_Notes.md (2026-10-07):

# AgriGuard B6 + B7 Reliability and Device Health Test

## Purpose

This test sketch validates the cloud-communication reliability layer without controlling irrigation.

- **B1:** NTP time synchronization
- **B2:** Device configuration/credential structure
- **B3:** Request UUID and nonce generation
- **B4:** Telemetry payload structure
- **B5:** HTTPS client
- **B6:** HTTP retry/backoff and Wi-Fi recovery
- **B7:** Device heartbeat and cloud-health tracking

## Important safety boundary

The B6/B7 tester does **not** control valves or irrigation. Cloud connectivity must never become a single point of failure for the local irrigation controller.

## Fixes applied after HTTP 400 testing

### 1. Request ID UUID format

The previous generator produced:

`8-4-4-4-8`

which is not a valid UUID and was rejected by `ingest-telemetry-v2`.

The corrected generator produces an RFC 4122 version-4 UUID:

`8-4-4-4-12`

Example:

`9CF5019C-416A-4BD6-8A5B-49DF1BD6A123`

### 2. Telemetry timestamps

The backend accepts `recorded_at` timestamps only when they are valid ISO-8601 timestamps and within the configured five-minute freshness window.

The corrected telemetry now adds `recorded_at` to:

- every sensor reading
- the tank reading
- the system status object

Format:

`YYYY-MM-DDTHH:MM:SSZ`

### 3. HTTP error visibility

Non-2xx responses now print the response body returned by the Edge Function. This makes future API-contract failures directly diagnosable from Serial Monitor.

## Expected successful flow

```
ESP32
  |
  +-- Wi-Fi
  |
  +-- NTP time
  |
  +-- UUID + nonce
  |
  +-- telemetry JSON
  |
  +-- HTTPS POST
  v
ingest-telemetry-v2
  |
  +-- device authentication
  +-- request freshness
  +-- replay protection
  +-- payload validation
  +-- zone authorization
  v
ingest_telemetry_atomic()
  |
  +-- sensor_readings
  +-- tank_readings
  +-- system_status
  +-- devices.last_seen_at
  +-- device_request_nonces
```

## Security

Never commit:

- the real device API key
- Supabase service-role keys
- dashboard secrets
- private credentials

Use local configuration or a secure provisioning mechanism for real credentials.

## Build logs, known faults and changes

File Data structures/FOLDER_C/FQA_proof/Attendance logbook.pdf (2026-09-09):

## Attendance logbook

| [2026-09-03] | [20:30 - 21:30] | [robo_Labs] | [Asked about whether there are research
that show the need for my solution, also advised that I should ask people in this field if
the solution would be viable] | [Link to screenshot] (https://www.builders.co.za/Fasteners-and-Adhesives/Fasteners/Plastic-Tubing/Waterhouse-PVC-Tubing-Clear-5000-x-12-mm/p/000000000000780314) |

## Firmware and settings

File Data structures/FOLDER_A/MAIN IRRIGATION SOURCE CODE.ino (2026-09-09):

#include <Arduino.h>
#include <WiFi.h>
#include <HTTPClient.h>
#include <ArduinoJson.h>

/*
============================================================
                    AGRIGUARD
             SMART IRRIGATION SYSTEM
============================================================

SYSTEM SECTIONS
------------------------------------------------------------
1. Pin configuration
2. Constants
3. Enumerations
4. Data structures
5. Global variables
6. Soil moisture system
7. Weather API
8. Water tank monitoring
9. Flow sensor
10. Water budgeting
11. Irrigation profile / learning
12. Irrigation decision engine
13. Irrigation state machine
14. Emergency stop
15. System setup
16. Main loop
============================================================
*/


// ============================================================
// 1. PIN CONFIGURATION
// ============================================================

// Soil sensors
#define SOIL_SENSOR_1 34
#define SOIL_SENSOR_2 35
#define SOIL_SENSOR_3 36

// Water tank ultrasonic sensor
#define TANK_TRIGGER_PIN 12
#define TANK_ECHO_PIN    14

// Irrigation valves for 3 zones
#define ZONE1_VALVE_PIN 26
#define ZONE2_VALVE_PIN 27
#define ZONE3_VALVE_PIN 33

// Flow sensor
#define FLOW_SENSOR_PIN 32

// EMERGENCY STOP
#define E_STOP_PIN 25
#define RESET_BUTTON_PIN 13


// ============================================================
// 2. SYSTEM CONSTANTS
// ============================================================

// ---------------- SOIL ----------------

const int SAMPLE_SIZE = 10;
const unsigned long SOIL_RECORD_INTERVAL = 30UL * 60UL * 1000UL;         // 30 minutes
const float WATER_LEVEL_LIMIT = 30.0;

// ---------------- WEATHER ----------------

const int DAILY_DATA = 48;
const unsigned long WEATHER_INTERVAL = 60UL * 60UL * 1000UL;         // 1 hour

// Rain probability above this value
const float RAIN_THRESHOLD = 60.0;

// ---------------- TANK ----------------

const unsigned long TANK_RECORD_INTERVAL = 60UL * 60UL * 1000UL;         // 1 hour
const float TANK_RESERVE_PERCENT = 30.0;

// ---------------- FLOW SENSOR ----------------

const float PULSES_PER_LITRE = 450.0;
const unsigned long FLOW_RATE_WINDOW = 5000UL;

// ---------------- IRRIGATION ----------------

const int MAX_IRRIGATION_CYCLES = 3;
const unsigned long SAFETY_TIMEOUT = 60UL * 60UL * 1000UL;         // 1 hour
const unsigned long SETTLING_TIME = 5UL * 60UL * 1000UL;           // 5 minutes

// ---------------- LEARNING ----------------

const int IRRIGATION_HISTORY_SIZE = 10;
const float DEMAND_HORIZON_HOURS = 24.0;

// ---------------- THRESHOLD COEFFICIENTS ----------------

const float TEMP_COEFFICIENT = 3.97;
const float HUMIDITY_COEFFICIENT = 5.97;
const float DRYING_RATE_COEFFICIENT = 7.96;

// ============================================================
// 3. ENUMERATIONS
// ============================================================

enum SoilType { CLAY, SANDY, LOAMY };
enum TankModel { JJ1, JJ2, JJ3, JJ4, JJ5, JJ6 };
enum IrrigationState { IDLE, WATERING, SETTLING, CHECKING, MAX_CYCLES_REACHED, EMERGENCY_STOP };


// ============================================================
// 4. DATA STRUCTURES
// ============================================================

// ------------------------------------------------------------
// SOIL ZONE
// ------------------------------------------------------------

struct Zone {
    int zoneID;
    SoilType soilType;
    float dryCalibration;
    float wetCalibration;
    float soilMoistureData[SAMPLE_SIZE];
    unsigned long timeStampData[SAMPLE_SIZE];
    int sampleCount;
    float soilPlaceHolder;
    float timePlaceHolder;
    float currentSoilMoisture;
    float newSoilReading;
    float avgSoilMoisture;
    float dryingRate;
    bool valveStatus;
    int sensorPin;
    int valvePin;
};

// ------------------------------------------------------------
// WEATHER DATA
// ------------------------------------------------------------

struct WeatherData {
    String timeStamp;
    float temperature;
    float humidity;
    float rainProbability;
};

// ------------------------------------------------------------
// TANK PROFILE
// ------------------------------------------------------------

struct TankProfile {
    String manufacturer;
    int volume;          // Litres
    float height;        // cm
    float diameter;      // cm
};

// ------------------------------------------------------------
// CURRENT WATER TANK
// ------------------------------------------------------------

struct WaterTank {
    TankModel model;
    float echoTime;
    float distance;
    float waterHeight;
    float waterPercentage;
    float volume;
};

// ------------------------------------------------------------
// IRRIGATION PROFILE
// ------------------------------------------------------------

struct IrrigationProfile {
    int zoneID;
    float preWateringMoisture;
    float postWateringMoisture;
    float nextMoisture;
    float waterSpent;
    float litresPerMoisture[IRRIGATION_HISTORY_SIZE];
    float dryingRates[IRRIGATION_HISTORY_SIZE];
    unsigned long irrigationDurations[IRRIGATION_HISTORY_SIZE];
    float waterUsedHistory[IRRIGATION_HISTORY_SIZE];
    float averageLitresPerPercentage;
    float averageDryingRate;
    float averageWaterPerCycle;
    float averageCycleDuration;
    int irrigationCycles;
    float minTemperature;
    float maxTemperature;
    float maximumHumidity;
    float maximumRainProbability;
};

// ------------------------------------------------------------
// WATER BUDGET
// ------------------------------------------------------------

struct WaterBudget {
    float tankCapacity;
    float currentWater;
    float reservedWater;
    float usableWater;
    float predictedDemand;
};


// ============================================================
// 5. GLOBAL VARIABLES
// ============================================================

Zone zones[3];
WeatherData weather[DAILY_DATA];
WaterTank waterTank;
WaterBudget waterBudget;
IrrigationProfile irrigationProfile;

// ------------------------------------------------------------
// TANK PROFILES
// ------------------------------------------------------------

//Different JOJO tank sizes
TankProfile tankProfiles[] = {
    {"JoJo", 2000, 145.0, 142.0},
    {"JoJo", 5250, 225.5, 182.0},
    {"JoJo", 5500, 224.0, 190.0},
    {"JoJo", 10000, 315.0, 220.0},
    {"JoJo", 15000, 326.0, 260.0},
    {"JoJo", 20000, 427.0, 260.0}
};

// ------------------------------------------------------------
// TIMERS
// ------------------------------------------------------------

unsigned long soilTimer = 0;
unsigned long weatherTimer = 0;
unsigned long tankTimer = 0;

// ------------------------------------------------------------
// WEATHER STATUS
// ------------------------------------------------------------

bool weatherAvailable = false;
int currentWeatherIndex = 0;

// ------------------------------------------------------------
// FLOW SENSOR VARIABLES
// ------------------------------------------------------------

volatile unsigned long flowPulses = 0;
unsigned long flowWindowPulses = 0;
unsigned long flowWindowStart = 0;
float currentFlowRate = 0.0;

// ------------------------------------------------------------
// IRRIGATION VARIABLES
// ------------------------------------------------------------

IrrigationState irrigationState = IDLE;
unsigned long irrigationStartTime = 0;
unsigned long settlingStartTime = 0;
int irrigationCycles = 0;
float requiredWater = 0.0;

// ------------------------------------------------------------
// EMERGENCY STOP
// ------------------------------------------------------------

bool emergencyStopActive = false;


// ============================================================
// 6. SOIL MOISTURE SYSTEM
// ============================================================

float convertRawSoilToPercentage(Zone &zone, float rawValue) {
    float moisture = 0;
    if (zone.dryCalibration == zone.wetCalibration) {
        return 0;
    }
    moisture = (zone.dryCalibration - rawValue) / (zone.dryCalibration - zone.wetCalibration) * 100.0;
    if (moisture > 100) moisture = 100;
    if (moisture < 0) moisture = 0;
    return moisture;
}

// ------------------------------------------------------------
// RECORD SOIL SENSOR
// ------------------------------------------------------------

void recordSoilData(Zone &zone) {
    if (millis() - soilTimer < SOIL_RECORD_INTERVAL) {
        return;
    }
    soilTimer = millis();
    float rawValue = analogRead(zone.sensorPin);
    float moisture = convertRawSoilToPercentage(zone, rawValue);
    zone.soilPlaceHolder = rawValue;
    zone.timePlaceHolder = millis();
    zone.currentSoilMoisture = moisture;
    
    // Store historical reading
    if (zone.sampleCount < SAMPLE_SIZE) {
        int index = zone.sampleCount;
        zone.soilMoistureData[index] = moisture;
        zone.timeStampData[index] = millis() / 60000UL;       //Converts time to minutes  
        zone.sampleCount++;
    } else {
        // Shift old readings out
        for (int a = 0; a < SAMPLE_SIZE - 1; a++) {
            zone.soilMoistureData[a] = zone.soilMoistureData[a + 1];
            zone.timeStampData[a] = zone.timeStampData[a + 1];
        }
        zone.soilMoistureData[SAMPLE_SIZE - 1] = moisture;
        zone.timeStampData[SAMPLE_SIZE - 1] = millis() / 60000UL;
    }
    
    Serial.println();
    Serial.println("===== SOIL SENSOR =====");
    Serial.print("Zone: ");
    Serial.println(zone.zoneID);
    Serial.print("Raw: ");
    Serial.println(rawValue);
    Serial.print("Moisture: ");
    Serial.print(moisture);
    Serial.println("%");
    Serial.print("Samples: ");
    Serial.println(zone.sampleCount);
}

// ------------------------------------------------------------
// CALCULATE AVERAGE SOIL MOISTURE
// ------------------------------------------------------------

float getAverageSoilMoisture(Zone &zone) {
    if (zone.sampleCount == 0) {
        return 0;
    }
    float total = 0;
    for (int i = 0; i < zone.sampleCount; i++) {
        total += zone.soilMoistureData[i];
    }
    return total / zone.sampleCount;
}

// ------------------------------------------------------------
// CALCULATE DRYING RATE
// ------------------------------------------------------------

float getDryingRate(Zone &zone) {
    if (zone.sampleCount < 2) {
        return 0;
    }
    int last = zone.sampleCount - 1;
    float moistureChange = zone.soilMoistureData[0] - zone.soilMoistureData[last];
    float timeChange = zone.timeStampData[last] - zone.timeStampData[0];
    if (timeChange <= 0) {
        return 0;
    }
    zone.dryingRate = abs(moistureChange / timeChange);
    return zone.dryingRate;
}

// ------------------------------------------------------------
// GET NEW SOIL READING
// Used after irrigation
// ------------------------------------------------------------

void getNewSoilReading(Zone &zone) {
    float rawValue = analogRead(zone.sensorPin);
    zone.newSoilReading = convertRawSoilToPercentage(zone, rawValue);
    zone.currentSoilMoisture = zone.newSoilReading;
    Serial.print("New soil moisture: ");
    Serial.print(zone.newSoilReading);
    Serial.println("%");
}

// ============================================================
// 7. WEATHER API
// ============================================================

// ------------------------------------------------------------
// WiFi credentials
// ------------------------------------------------------------

const char* WIFI_SSID = "";
const char* WIFI_PASSWORD = "";

// ------------------------------------------------------------
// Agriguard location
// ------------------------------------------------------------

const float LAT = -29.35080374459709;
const float LON = 27.601807742259524;

// ------------------------------------------------------------
// CONNECT WIFI
// ------------------------------------------------------------

void connectWiFi() {
    if (WiFi.status() == WL_CONNECTED) {
        return;
    }
    Serial.println("Connecting to WiFi...");
    WiFi.begin(WIFI_SSID, WIFI_PASSWORD);
    unsigned long startAttempt = millis();
    while (WiFi.status() != WL_CONNECTED && millis() - startAttempt < 10000) {
        delay(500);
        Serial.print(".");
    }
    Serial.println();
    if (WiFi.status() == WL_CONNECTED) {
        Serial.println("WiFi connected.");
        Serial.print("IP: ");
        Serial.println(WiFi.localIP());
    } else {
        Serial.println("WiFi connection failed.");
    }
}

// ------------------------------------------------------------
// BUILD WEATHER API URL
// ------------------------------------------------------------

//Connection String
String buildWeatherURL() {
    String API_URL = "https://api.open-meteo.com/v1/forecast?latitude=" + String(LAT) + "&longitude=" + String(LON) + 
    "&hourly=temperature_2m,relative_humidity_2m,precipitation_probability,precipitation&forecast_days=2&timezone=auto";
    
    return API_URL;
}

// ------------------------------------------------------------
// GET WEATHER DATA
// ------------------------------------------------------------

void getWeatherData() {
    if (WiFi.status() != WL_CONNECTED) {
        weatherAvailable = false;
        return;
    }
    HTTPClient http;          //This object will enable the system to make HTTP requests
    String url = buildWeatherURL();
    Serial.println();
    Serial.println("===== WEATHER API =====");
    Serial.println(url);
    http.setConnectTimeout(5000);  // 5s to establish connection
    http.setTimeout(10000);         // 10 sec waiting for data
    http.begin(url);
    int httpCode = http.GET();        //Creates a connection to send the HTTP request
    
    //Confirms if data was recieved
    if (httpCode == HTTP_CODE_OK) {
        String jsonData = http.getString();      //Reads data 
        DynamicJsonDocument doc(16384);
        DeserializationError error = deserializeJson(doc, jsonData);
        if (error) {
            Serial.print("JSON error: ");
            Serial.println(error.c_str());
            weatherAvailable = false;
            http.end();
            return;
        }
        JsonObject jsonOb = doc.as<JsonObject>();
        for (int a = 0; a < DAILY_DATA; a++) {
            weather[a].timeStamp = jsonOb["hourly"]["time"][a].as<String>();
            weather[a].temperature = jsonOb["hourly"]["temperature_2m"][a].as<float>();
            weather[a].humidity = jsonOb["hourly"]["relative_humidity_2m"][a].as<float>();
            weather[a].rainProbability = jsonOb["hourly"]["precipitation_probability"][a].as<float>();
        }
        currentWeatherIndex = 0;
        weatherAvailable = true;
        //Other random stuff
        Serial.println("Weather data updated.");
        Serial.print("Temperature: ");
        Serial.println(weather[0].temperature);
        Serial.print("Humidity: ");
        Serial.println(weather[0].humidity);
        Serial.print("Rain probability: ");
        Serial.println(weather[0].rainProbability);
    } else {
        Serial.print("Weather HTTP error: ");
        Serial.println(httpCode);
        weatherAvailable = false;
    }
    http.end();
}

// ------------------------------------------------------------
// CURRENT WEATHER
// ------------------------------------------------------------

WeatherData getCurrentWeather() {
    return weather[currentWeatherIndex];
}

// ============================================================
// 8. WATER TANK SYSTEM
// ============================================================

// ------------------------------------------------------------
// RECORD ULTRASONIC DATA
// ------------------------------------------------------------

// Read ultrasonic sensor
void recordTankData() {
    digitalWrite(TANK_TRIGGER_PIN, LOW);
    delayMicroseconds(2);
    digitalWrite(TANK_TRIGGER_PIN, HIGH);
    delayMicroseconds(10);
    digitalWrite(TANK_TRIGGER_PIN, LOW);
    waterTank.echoTime = pulseIn(TANK_ECHO_PIN, HIGH, 30000);
}

// ------------------------------------------------------------
// CONVERT DISTANCE
// ------------------------------------------------------------

// Convert echo time into distance
void convertTankDistance() {
    waterTank.distance = (waterTank.echoTime * 0.0343) / 2.0;       //The 0.0343 is the speed of sound
}

// ------------------------------------------------------------
// CALCULATE WATER LEVEL
// ------------------------------------------------------------

void calculateWaterLevel() {
    TankProfile currentTank = tankProfiles[waterTank.model];
    waterTank.waterHeight = currentTank.height - waterTank.distance;
    // Prevent invalid values
    if (waterTank.waterHeight < 0) {
        waterTank.waterHeight = 0;
    }
    if (waterTank.waterHeight > currentTank.height) {
        waterTank.waterHeight = currentTank.height;
    }
    waterTank.waterPercentage = (waterTank.waterHeight / currentTank.height) * 100.0;
    if (waterTank.waterPercentage > 100) waterTank.waterPercentage = 100;
    if (waterTank.waterPercentage < 0) waterTank.waterPercentage = 0;
    waterTank.volume = (waterTank.waterPercentage / 100.0) * currentTank.volume;
}

// ------------------------------------------------------------
// UPDATE TANK
// ------------------------------------------------------------

void updateTank() {
    if (millis() - tankTimer < TANK_RECORD_INTERVAL) {
        return;
    }
    tankTimer = millis();
    recordTankData();
    convertTankDistance();
    calculateWaterLevel();
    TankProfile currentTank = tankProfiles[waterTank.model];
    Serial.println();
    Serial.println("===== WATER TANK =====");
    Serial.print("Tank capacity: ");
    Serial.print(currentTank.volume);
    Serial.println(" L");
    Serial.print("Distance: ");
    Serial.print(waterTank.distance);
    Serial.println(" cm");
    Serial.print("Water height: ");
    Serial.print(waterTank.waterHeight);
    Serial.println(" cm");
    Serial.print("Water level: ");
    Serial.print(waterTank.waterPercentage);
    Serial.println("%");
    Serial.print("Estimated water: ");
    Serial.print(waterTank.volume);
    Serial.println(" L");
}

// ============================================================
// 9. FLOW SENSOR
// ============================================================

// Interrupt function
void IRAM_ATTR countFlowPulse() {
    flowPulses++;
}

// ------------------------------------------------------------
// GET TOTAL WATER VOLUME
// ------------------------------------------------------------

// Stuff from flow sensor
float getWaterVolume() {
    noInterrupts();        //This pauses/holds interrupts to count pulses
    unsigned long pulses = flowPulses;
    interrupts();
    float convPulse = 0;
    convPulse = pulses / PULSES_PER_LITRE;      //Converts pulses into litres
    return convPulse;
}
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
void loop() {
    // ========================================================
    // HIGHEST PRIORITY:
    // EMERGENCY STOP
    // ========================================================

    emergencyStop();
    if (emergencyStopActive) {
        // Do not allow normal irrigation logic to execute
        return;
    }
    if (irrigationState == EMERGENCY_STOP) {
        handleEmergencyStop();
        resetEmergencyStop();
        return;
    }

    // ========================================================
    // SENSOR SYSTEMS
    // ========================================================

    for (int i = 0; i < 3; i++) {
        recordSoilData(zones[i]);
    }
    updateTank();

    // ========================================================
    // WEATHER
    // ========================================================

    if (millis() - weatherTimer >= WEATHER_INTERVAL) {
        weatherTimer = millis();
        connectWiFi();
        getWeatherData();
    }

    // ========================================================
    // UPDATE SOIL AVERAGE
    // ========================================================

    for (int i = 0; i < 3; i++) {
        if (zones[i].sampleCount > 0) {
            zones[i].avgSoilMoisture = getAverageSoilMoisture(zones[i]);
        }
    }

    // ========================================================
    // IRRIGATION STATE MACHINE - Process each zone
    // ========================================================

    for (int i = 0; i < 3; i++) {
        switch (irrigationState) {
            case IDLE:
                if (shouldStartIrrigation(zones[i])) {
                    startIrrigation(zones[i]);
                }
                break;
            case WATERING:
                updateWatering(zones[i]);
                break;
            case SETTLING:
                updateSettling(zones[i]);
                break;
            case CHECKING:
                irrigationState = IDLE;
                break;
            case MAX_CYCLES_REACHED:
                digitalWrite(zones[i].valvePin, LOW);
                zones[i].valveStatus = false;
                Serial.println("Maximum irrigation cycles reached.");
                irrigationState = IDLE;
                break;
            case EMERGENCY_STOP:
                handleEmergencyStop();
                break;
        }
    }

    // ========================================================
    // WATER BUDGET
    // ========================================================

    updateWaterBudget();
    if (irrigationState == IDLE) {
        waterBudget.predictedDemand = predictWaterDemand(zones[0]);
    }

    // ========================================================
    // STATUS
    // ========================================================

    static unsigned long statusTimer = 0;
    if (millis() - statusTimer >= 30000UL) {
        statusTimer = millis();
        displaySystemStatus();
    }
}

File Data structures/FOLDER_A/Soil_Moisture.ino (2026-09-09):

//SENSOR DATA
#define sensorOutPut 12      //We get soil moisture data
const int sampleSize = 10;    //Come back to find how many record you actual need  
unsigned long timeCount = 0;
const int soil_TimeStamp = 1800000;         //Record soil moisture data 30m
const int DAILY_DATA = 48;
int rain_threshold = 60;
int waterLvl_limit = 30;
int arrIndx = 0;

enum SoilType{
  CLAY, 
  SANDY, 
  LOAMY
};

struct Zone{
  SoilType soilTyp;
  float dryCalibration;         //To calibrate the sensor to get minimum value 
  float wetCalibration;         //To calibrate the sensor to get maximum value
  float soilMoistureData[sampleSize];             //Stores 10 samples of soil moisture readings
  float avgSoilMoisture;        //Average soil moisture
  unsigned long timeStampData[sampleSize];        //Stores the timestamps of when data was collected
  float timePlaceHolder;
  float soilPlaceHolder;                          //Temporary location for holding data before storing it permanently. 
  bool valveStatus;
  float newSoilReading;                   //Stores new sensor readings for getting Stop Irrigation
};

//Weather Class
struct weather_API{
  String time_Stamp;
  float API_temp;
  float API_humidity;
  float rain_prob;
};

weather_API weather[DAILY_DATA];

//Water level stuff
struct WaterTank
{
    //TankModel model;
    //float echoTime;
    //float distance;
    //float waterHeight;
    float waterPercentage;
};

WaterTank tank[DAILY_DATA];

//Zone zone1;                     //Zone object

void recordSoilData(Zone& zone){          //This function will record data from sensors.
    
    //This condition checks if the time difference between when it started and when it last recorded data is 30m
    if(millis() - timeCount >= soil_TimeStamp){     
      timeCount = millis();
       zone.soilPlaceHolder = analogRead(sensorOutPut);
      zone.timePlaceHolder = timeCount;   
    }  
}

void convertData(Zone& zone){          //This function converts raw data into percentages and stores them.
    float placeholder = 0;

    placeholder = (zone.dryCalibration - zone.soilPlaceHolder) / (zone.dryCalibration - zone.wetCalibration) * 100;      //Convert each data into a percentage

    if(placeholder < 0){
      placeholder = 0;
    }
    else if(placeholder > 100){
      placeholder = 100;
    }

  if(arrIndx < sampleSize){
    zone.soilMoistureData[arrIndx] = placeholder;
    zone.timeStampData[arrIndx] = zone.timePlaceHolder / 60000;       //Converts the millis time into minutes.
    arrIndx++;

  } else if(arrIndx >= sampleSize){
    arrIndx = 0;
  }

}

float getDryingRate(Zone& zone) {          //This function will determine the drying rates of the soil.

  float soil_dryRate = 0.0;

 //This ensure that it gets the rate after all 10 records have been read
  if(arrIndx == sampleSize-1){
    soil_dryRate = abs((zone.soilMoistureData[sampleSize-1] - zone.soilMoistureData[0]) / (zone.timeStampData[sampleSize-1] - zone.timeStampData[0]));  //abs() to ensure that we don't get a negative drying rate. 
  }
  else{
    Serial.println("Not all 10 readings have been made!");
  }

  return soil_dryRate;
}

double getThreshold(Zone& zone){
  
  double soilThreshold = 0;
  double loamyB1_thresholds = 40;
  double clayB1_thresholds = 47;
  double SandyB1_thresholds = 27;
  float dryRate = getDryingRate(zone);
  float tempPrec = weather[arrIndx].API_temp;
  float humidPerc = weather[arrIndx].API_humidity;
  const double TEMP_COEFFICIENT = 3.97;              //Temperature coefficients to convert percentage into usable values
  const double HUMID_COEFFICIENT = 5.97;             //Humidity coefficients to convert percentage into usable values
  const double DRYING_RATE_COEFFICIENT = 7.96;       //Drying rate coefficients to convert percentage into usable values

  //Data effect stuff
 /*
  -> For temperature:
    We use 20 as a threshold adjuster and the (-1, +1) are for making sure extreme temperatures don't affect the calibration.

  -> For humidity:  
    We use 60 as a threshold adjuster and the (-1, +1) are for making sure extreme humidity don't affect the calibration.

  -> For drying rate:
    We use 60 as a threshold adjuster and the (-1, +1) are for making sure extreme drying rate don't affect the calibration.
  */ 
  float tempEffect = constrain((tempPrec - 20.0) / 15.0, -1.0, 1.0);

  float humidityEffect = constrain((60.0 - humidPerc) / 35.0, -1.0, 1.0);

  float dryingEffect = constrain((dryRate - 0.5) / 1.5, -1.0, 1.0);


 //This determines the threshold for every hour
  if(arrIndx < DAILY_DATA){
    if(zone.soilTyp == CLAY){
    soilThreshold = abs(clayB1_thresholds + (tempEffect * TEMP_COEFFICIENT) + (dryRate * DRYING_RATE_COEFFICIENT) - (humidPerc * HUMID_COEFFICIENT));
  } 
  else if(zone.soilTyp == SANDY){
    soilThreshold = abs(SandyB1_thresholds + (tempEffect * TEMP_COEFFICIENT) + (dryRate * DRYING_RATE_COEFFICIENT) - (humidPerc * HUMID_COEFFICIENT));
  }
  else if(zone.soilTyp == LOAMY){
    soilThreshold = abs(loamyB1_thresholds + (tempEffect * TEMP_COEFFICIENT) + (dryRate * DRYING_RATE_COEFFICIENT) - (humidPerc * HUMID_COEFFICIENT));
    }
  } 

  return soilThreshold;
}

//Create a condition that will first check if the number of elements is 10, then get the average of those elements and use it as your benchmark.
bool detIrrigation(Zone& zone){

  double threshold = getThreshold(zone);            //  This call the calculated threshold.
  double rain = weather[arrIndx].rain_prob;       
  float waterLvl = tank[arrIndx].waterPercentage;
  double counter = 0;       //Increments soil_moisture data
  bool weatherAvail = false;
  
  if(arrIndx < sampleSize){
    return false;         //Safegaurd to make sure we have 10 records
  }

  //This gets the average of soil moisture readings
 for(int a = 0; a < sampleSize; a++){
      counter += zone.soilMoistureData[a];
    }

    zone.avgSoilMoisture = counter/sampleSize;
    //Send and store the reading to memory.
    //Reset the reading after storing them.
    //Reset the arrIndx.

    //Checks if it has values 
   if(rain > 0){
    weatherAvail = true;
   }


  //Primary condition checking if soil and water_levl are true
  if(waterLvl > waterLvl_limit && zone.avgSoilMoisture < threshold){
  zone.valveStatus = true;

 //This will put irrigation on hold ir rain is expected
  if(weatherAvail && rain > rain_threshold){
    zone.valveStatus = false;
    }
  }
 else{
  zone.valveStatus = false;
 }

  return zone.valveStatus;

}

  Zone zone1;

void setup(){
 recordSoilData(zone1);
}


 void loop() {
  // put your main code here, to run repeatedly:
  //  Zone zone;
  getDryingRate(zone1);
  getThreshold(zone1);
  detIrrigation(zone1);
}

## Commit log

2026-08-03 Implement Weather API data retrieval
    This code connects to a WiFi network, retrieves weather data from the OpenWeatherMap API using latitude and longitude, and prints the weather description, temperature, and humidity to the Serial moni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
2026-08-08 Implement water tank monitoring logic
    This code implements a water tank monitoring system using ultrasonic sensors. It defines tank models, profiles, and includes functions to read data, calculate water levels, and display results.
2026-09-03 Add irrigation profile implementation
    This file contains the implementation of an irrigation profile system, including flow sensor handling, irrigation state management, and water budget calculations.
2026-09-06 Add emergency stop and system power logic
2026-09-07 Add Mechanical designs folder for CAD designs
2026-09-07 Add Pitch Deck to FOLDER_C
2026-09-07 Documented encapsulator design and assembly process
    Detailed the design, fabrication, and assembly process of the custom 3D-printed enclosure for Agriguard control electronics, including component fastening and electrical connections.
2026-09-30 Add main function to ESP32 project
2026-09-30 Add initial sensors file
2026-09-30 Add irrigation functionality to ESP32 project
2026-09-30 Add storage placeholder in ESP32/Storage
2026-10-07 Fix B6/B7 telemetry request UUID and diagnostics
    [sketch_tester.ino]
2026-10-07 Add corrected B6/B7 tester under Testing
    [sketch_tester.ino]
2026-10-10 Add farmer sign-up page prototype
2026-10-10 Add dashboard page prototype
